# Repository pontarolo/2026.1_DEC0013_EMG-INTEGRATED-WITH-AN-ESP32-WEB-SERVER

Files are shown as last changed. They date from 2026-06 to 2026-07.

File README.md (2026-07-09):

<div align="center">
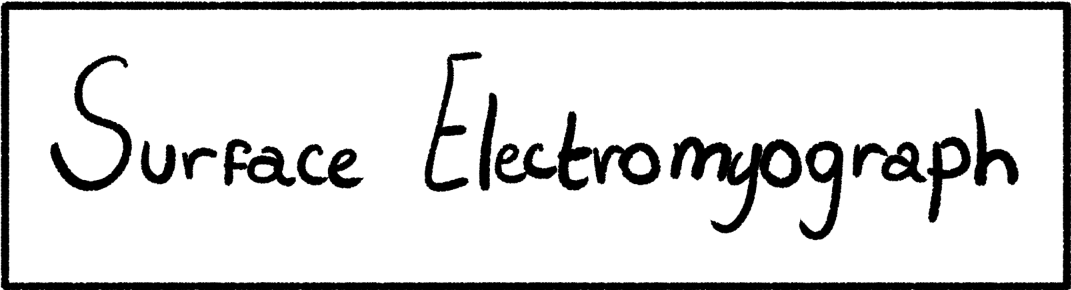
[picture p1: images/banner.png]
    
    

<h4 align="center">Electromyograph integrated with an ESP32 Web Server</h4>




</div>

<p align="center">
  <a href="#materials">Materials</a> •
  <a href="#diagrams">Diagrams</a> •
  <a href="software/README.md">Software</a> •
  <a href="LICENSE">License</a>
</p>

---

## Basic Overview

This project consists of an implementation of a circuit to measure specific muscle activity, consisting of two channels, which means that it is possible to measure two muscles simultaneously. The project emerges as a way to detect muscular issues and restraints in a low-cost and reliable manner. The general architecture of this project is a connection between the electromyograph PCB and the ESP32 microcontroller, where the ESP32 acts as a web server with an WebSocket to handle the data plotting. The GIF shown above was made from a video of the electromyograph in operation, which recorded the web page hosted by the ESP32.

## Goals

| Type | Goal |
| :--- | :--- |
| **Hardware** | Design a circuit that is capable of effectively measuring muscle voltage |
| **Hardware** | Make the circuit as noise-free as possible |
| **Software** | Write an optimized code that can display, in real time, the muscle data |

### Project Directory Structure

```text
├── hardware/             # PCB design files (symbols, footprints, models, and Gerbers)
│   ├── footprints/       # Custom component footprints (.kicad_mod)
│   ├── kicad_files/      # KiCad project files and manufacturing Gerbers
│   ├── models/           # 3D step files for components
│   └── symbols/          # Custom schematic symbol libraries (.kicad_sym)
├── images/               # Visual assets for documentation and tutorials
└── software/             # Firmware and source code for the project
    └── plot/             # ESP32 source code for data acquisition
```

## Description

This section explains the details of the project, including the materials and tools used, communication and electrical diagrams and examples of its functionality.

###  Materials

<table>
  <tr>
    <td align="center" valign="top" width="150" style="border: none;">
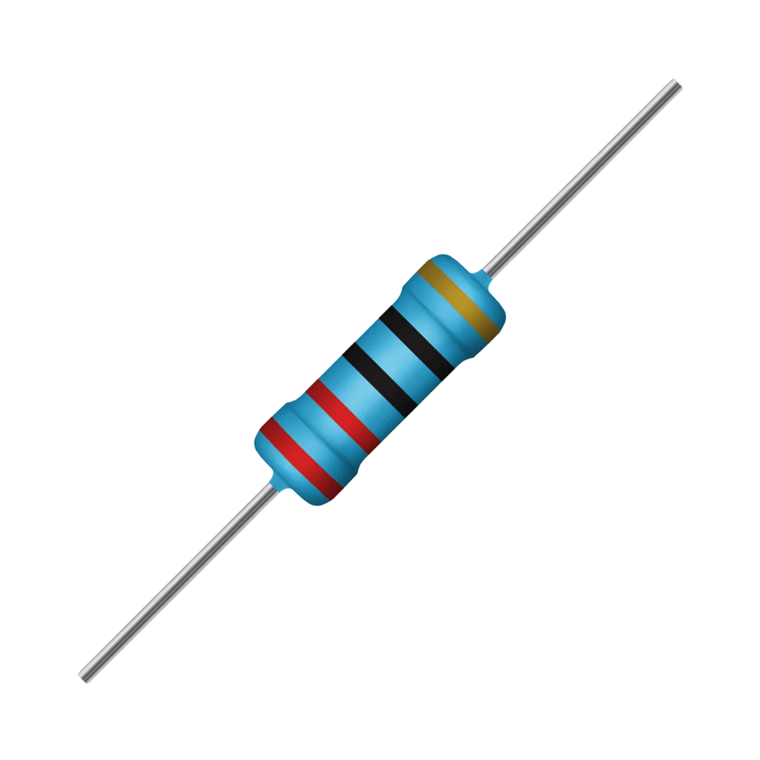
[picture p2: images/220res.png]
      <br>
      <strong>Resistor</strong><br>
      <font color="#666" size="2">2x 220Ω • 1/4 W • 5% • THT</font>
    </td>
    <td align="center" valign="top" width="150" style="border: none;">
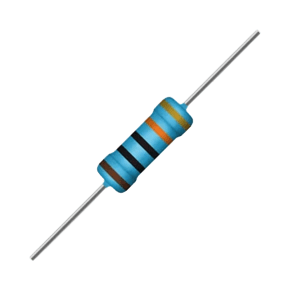
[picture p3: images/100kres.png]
      <br>
      <strong>Resistor</strong><br>
      <font color="#666" size="2">4x 100KΩ • 1/4 W • 5% • THT</font>
    </td>
    <td align="center" valign="top" width="150" style="border: none;">
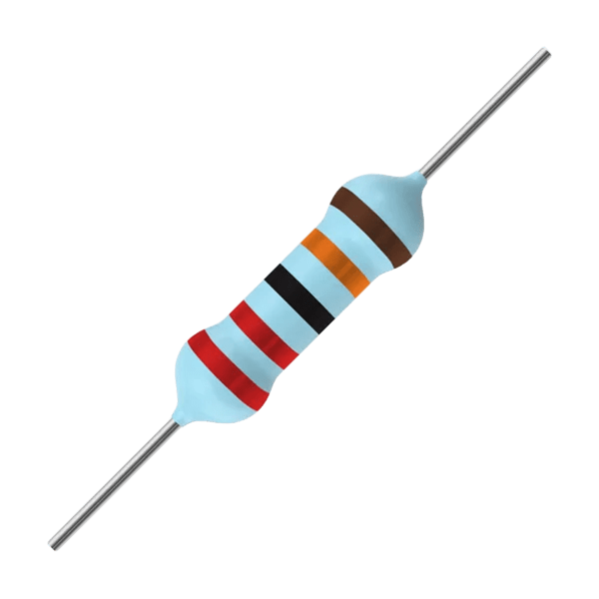
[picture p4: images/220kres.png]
      <br>
      <strong>Resistor</strong><br>
      <font color="#666" size="2">4x 220KΩ • 1/4 W • 5% • THT</font>
    </td>
    <td align="center" valign="top" width="150" style="border: none;">
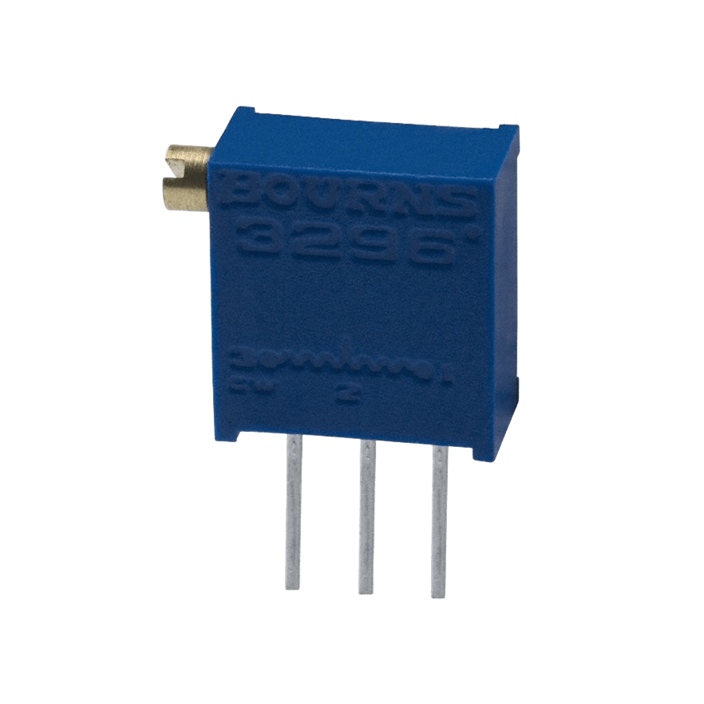
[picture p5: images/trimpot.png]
      <br>
      <strong>Trimpot</strong><br>
      <font color="#666" size="2">1x 10KΩ • THT</font>
    </td>
  </tr>
  <tr>
    <td align="center" valign="top" width="150" style="border: none;">
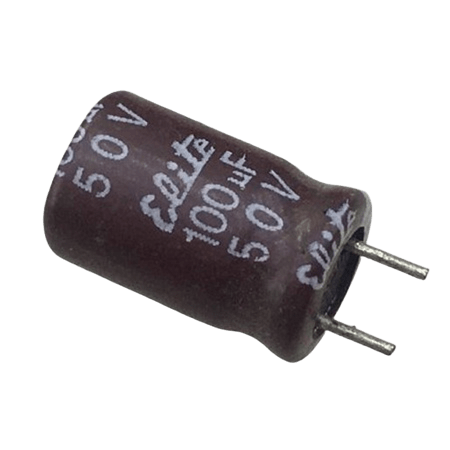
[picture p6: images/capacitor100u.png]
      <br>
      <strong>Capacitor</strong><br>
      <font color="#666" size="2">2x 100μF • Electrolytic • THT</font>
    </td>
    <td align="center" valign="top" width="150" style="border: none;">
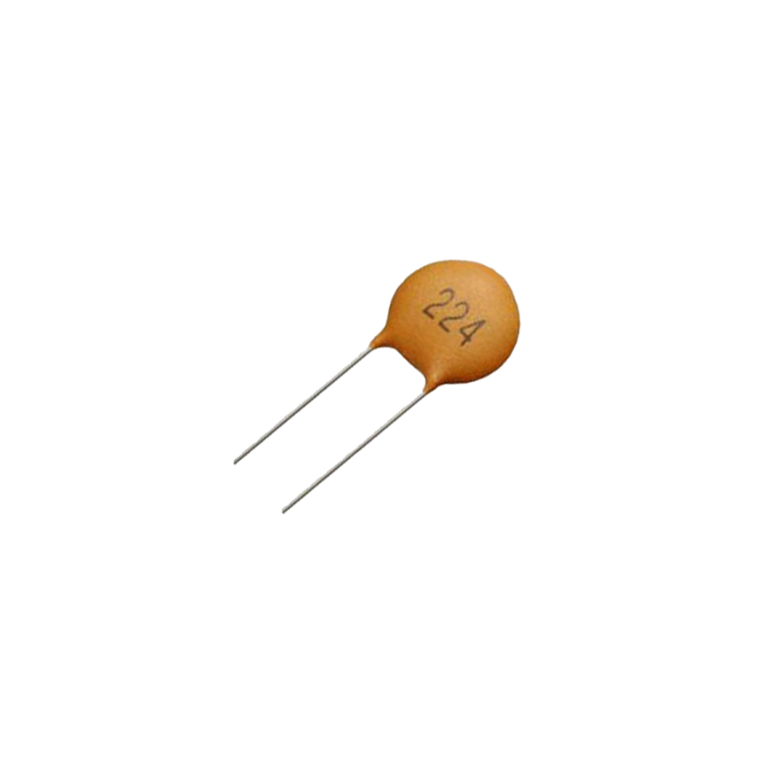
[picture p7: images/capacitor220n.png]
      <br>
      <strong>Capacitor</strong><br>
      <font color="#666" size="2">2x 220nF • Ceramic • THT</font>
    </td>
    <td align="center" valign="top" width="150" style="border: none;">
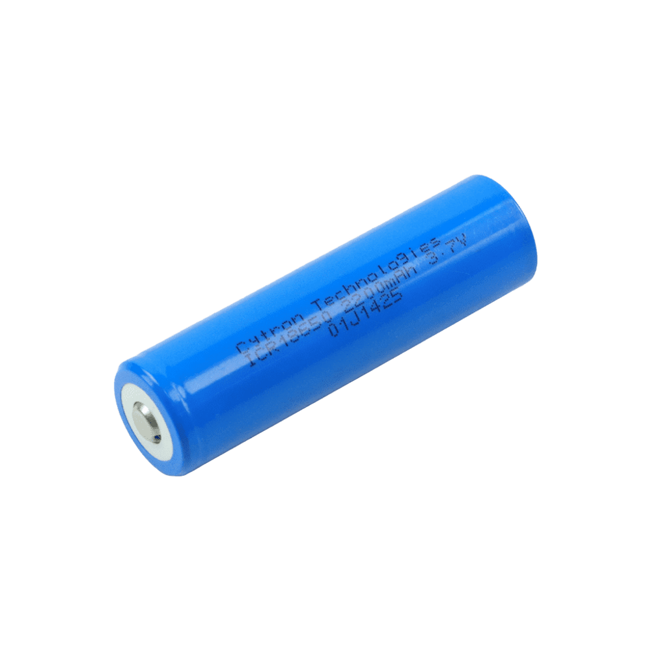
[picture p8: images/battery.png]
      <br>
      <strong>Battery</strong><br>
      <font color="#666" size="2">2x Lithium-Ion • 3.7V • 18650</font>
    </td>
    <td align="center" valign="top" width="150" style="border: none;">
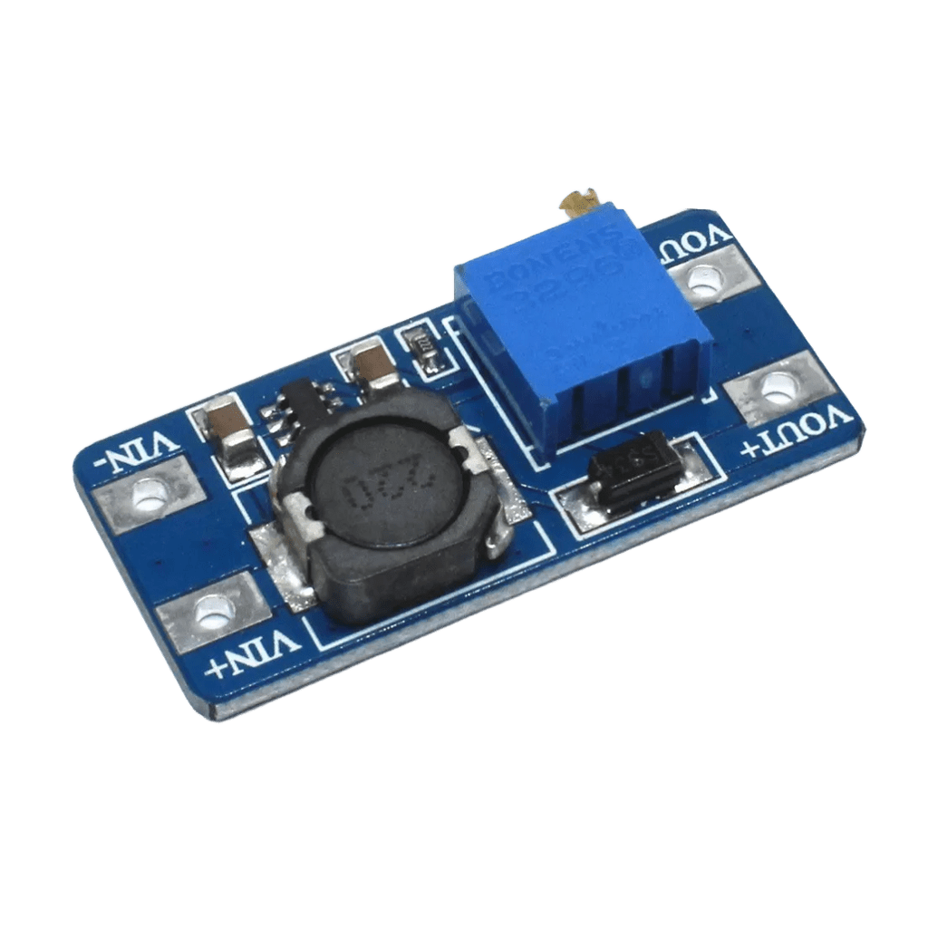
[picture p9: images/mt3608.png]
      <br>
      <strong>MT3608</strong><br>
      <font color="#666" size="2">1x Module</font>
    </td>
  </tr>
  <tr>
    <td align="center" valign="top" width="150" style="border: none;">
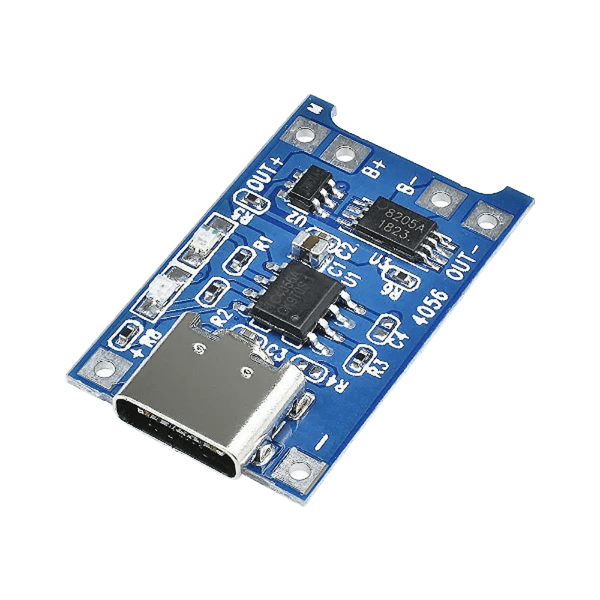
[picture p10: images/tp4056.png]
      <br>
      <strong>TP4056</strong><br>
      <font color="#666" size="2">1x Module</font>
    </td>
    <td align="center" valign="top" width="150" style="border: none;">
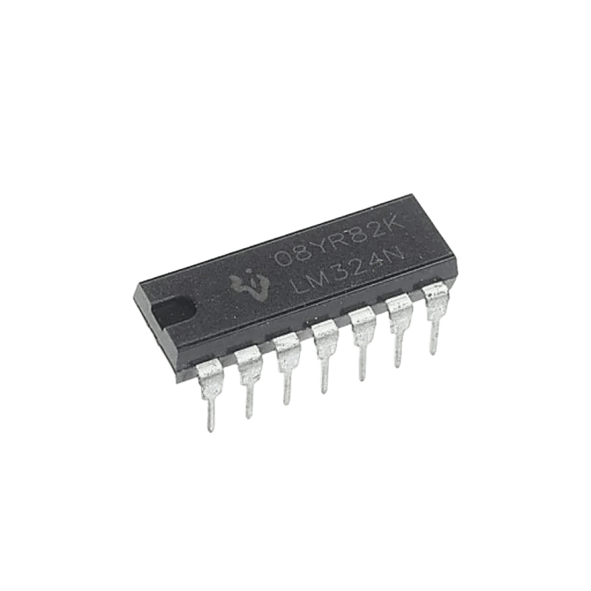
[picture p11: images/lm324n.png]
      <br>
      <strong>LM324N</strong><br>
      <font color="#666" size="2">1x Integrated Circuit</font>
    </td>
    <td align="center" valign="top" width="150" style="border: none;">
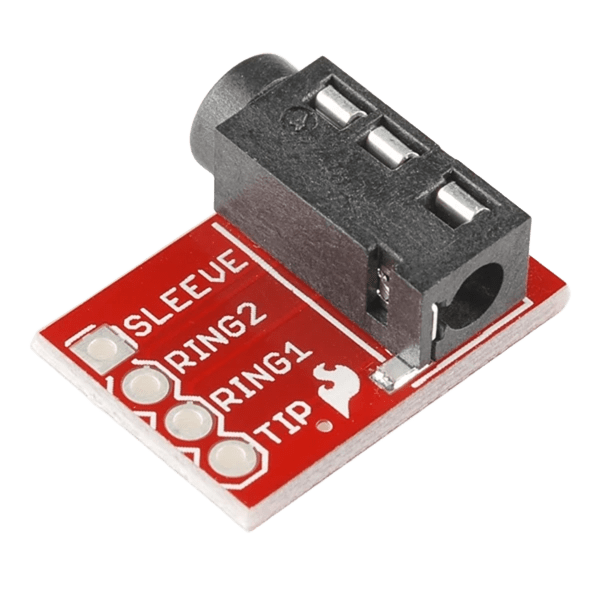
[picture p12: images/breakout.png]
      <br>
      <strong>TRRS Breakout</strong><br>
      <font color="#666" size="2">1x Module</font>
    </td>
    <td align="center" valign="top" width="150" style="border: none;">
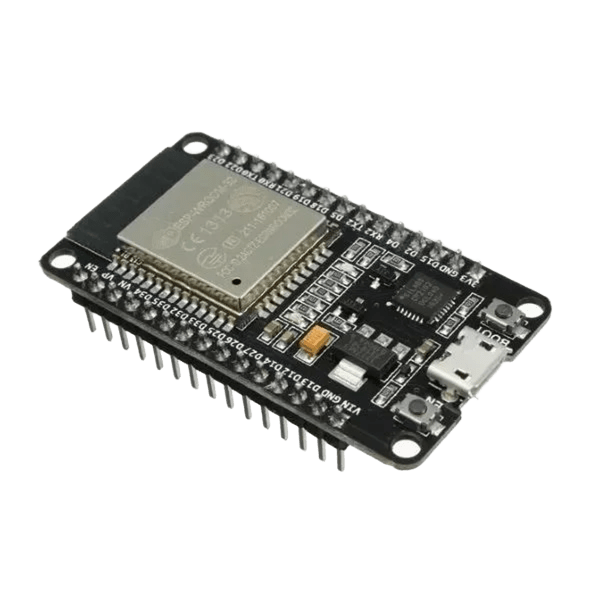
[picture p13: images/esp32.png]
      <br>
      <strong>ESP32</strong><br>
      <font color="#666" size="2">1x ESP-WROOM-32</font>
    </td>
  </tr>
  <tr>
    <td align="center" valign="top" width="150" style="border: none;">
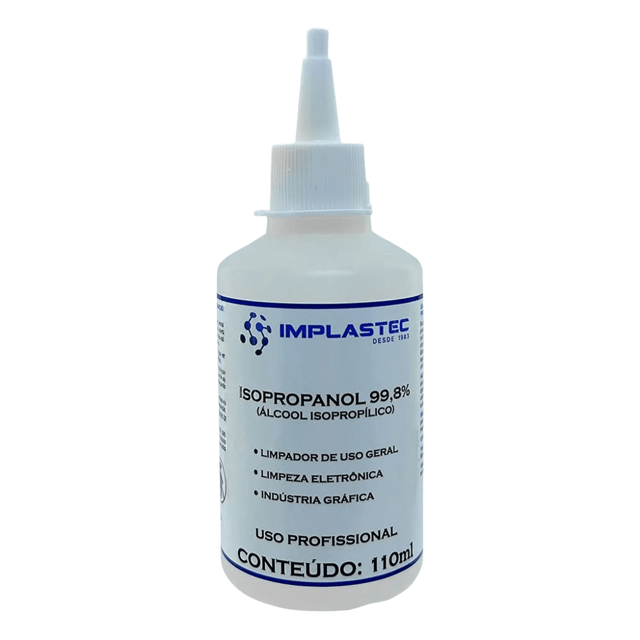
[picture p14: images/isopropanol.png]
      <br>
      <strong>Isopropanol</strong><br>
      <font color="#666" size="2">1x 99.8% Pure</font>
    </td>
    <td align="center" valign="top" width="150" style="border: none;">
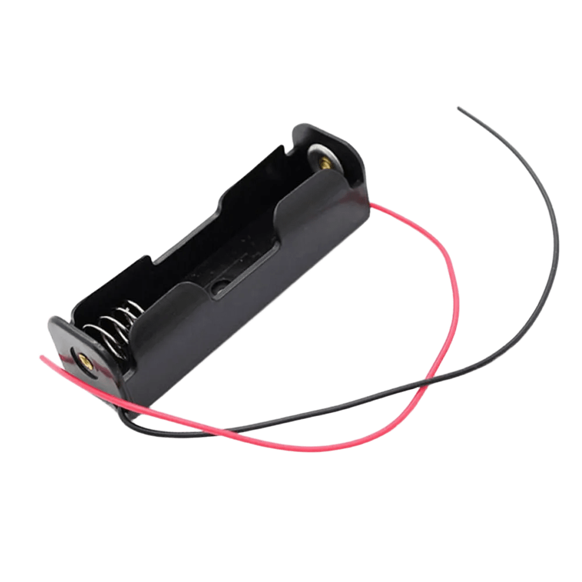
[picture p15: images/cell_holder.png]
      <br>
      <strong>Cell Holder</strong><br>
      <font color="#666" size="2">1x Lithium-Ion • 18650 • Single</font>
    </td>
    <td align="center" valign="top" width="150" style="border: none;">
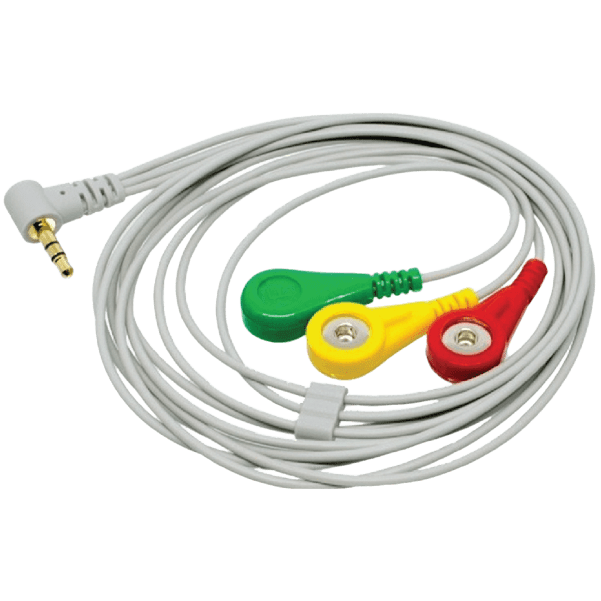
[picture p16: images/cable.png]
      <br>
      <strong>EMG Cable</strong><br>
      <font color="#666" size="2">2x P2 Connection</font>
    </td>
    <td align="center" valign="top" width="150" style="border: none;">
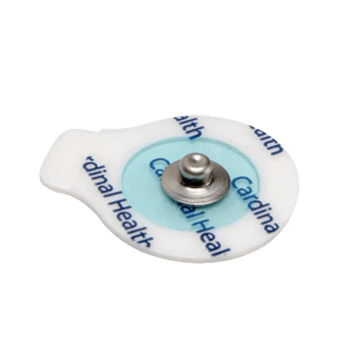
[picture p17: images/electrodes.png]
      <br>
      <strong>Electrodes</strong><br>
      <font color="#666" size="2">6x Disposable</font>
    </td>
  </tr>
</table>

###  Communication Diagram

In this subsection we will discuss the communication diagram of the project to give a general view of the signal path and a clearer understanding of the circuit itself.

<p align="center">
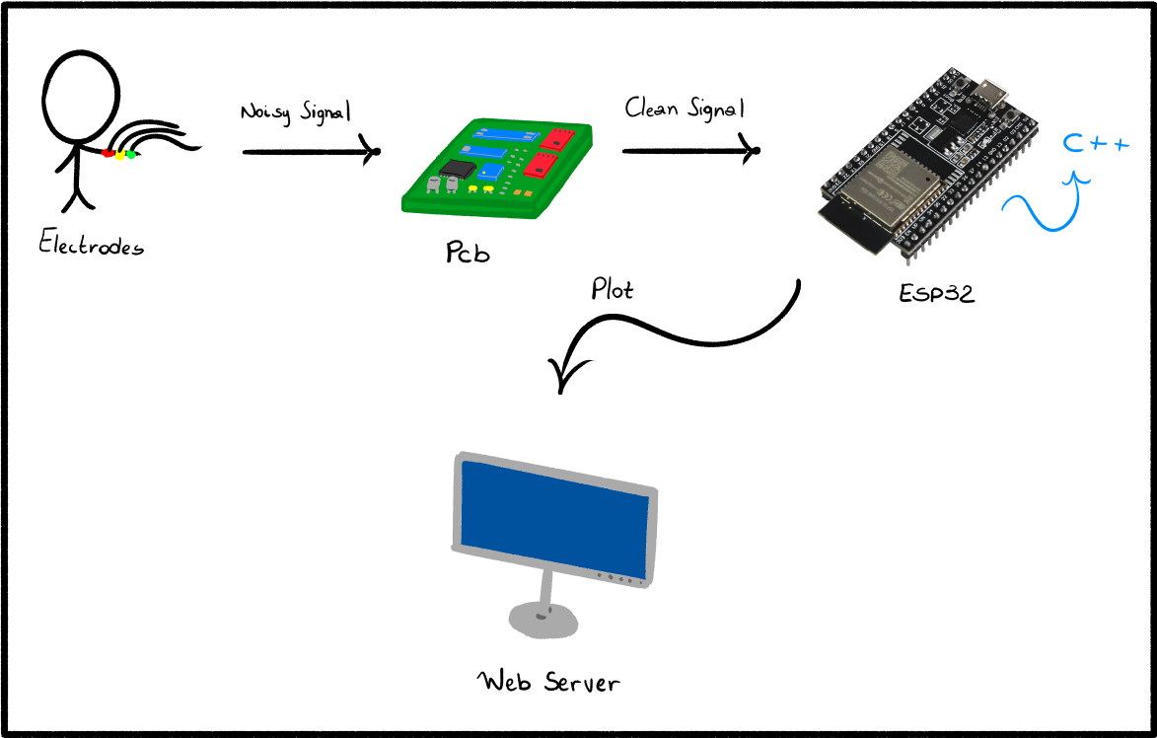
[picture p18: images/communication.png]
    
</p>

The image above represents the communication diagram, which shows the signal path throughout the whole project. The user's noisy low-voltage signal is sent to the printed circuit board (PCB) through silver $Ag$ or silver chloride $AgCl$ electrodes, where it can be properly filtered and amplified. Then the clean signal is carried to the ESP32 microcontroller that acts as a WebSocket Server to handle massive data plotting, hosting an HTML page that displays the graph.

---

###  Electrical Diagram

In this subsection we will discuss the communication diagram of the project to give a general view of the signal processing and a clearer understanding of the circuit itself.

<p align="center">
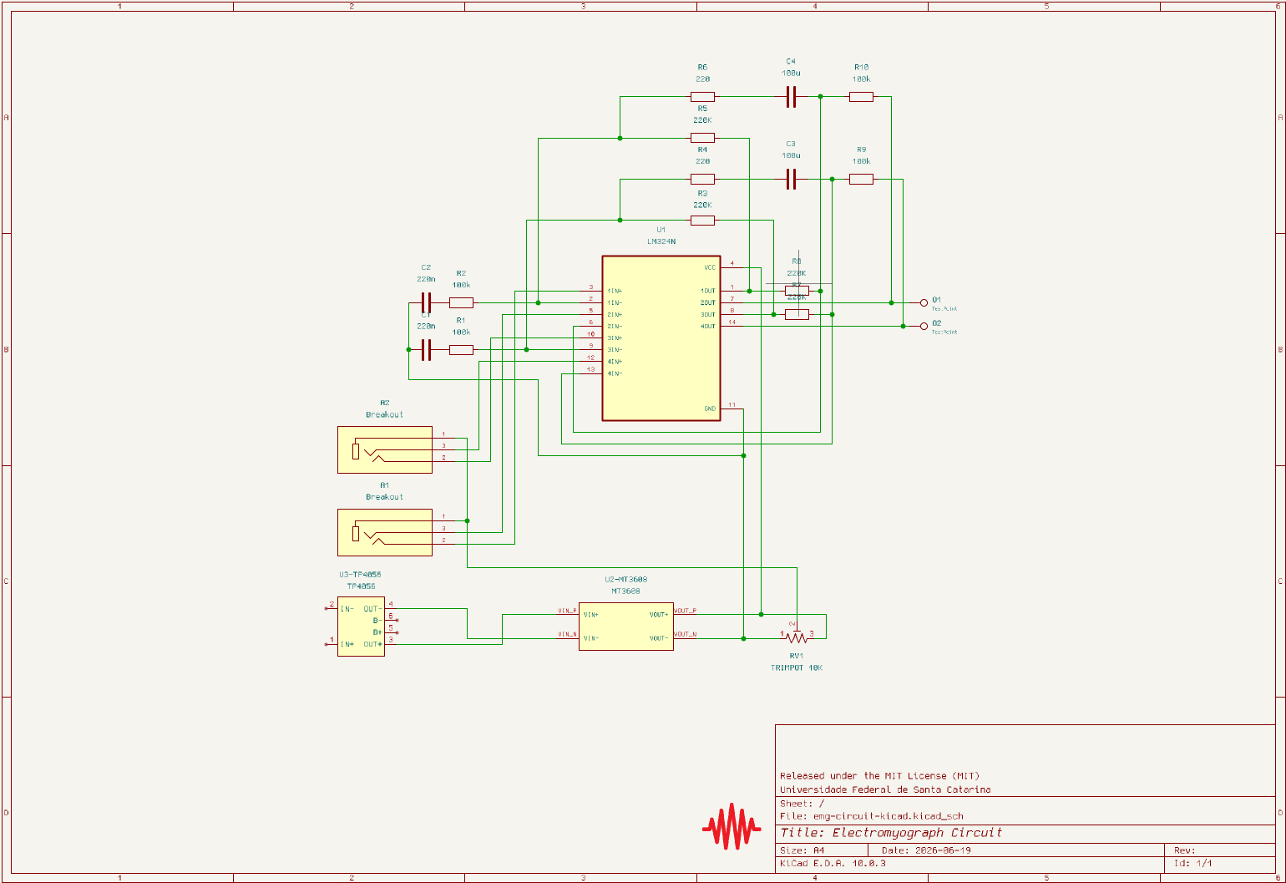
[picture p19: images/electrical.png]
    
</p>

The image above represents the electrical diagram, which shows the electrical connection between the components. As shown in the image, the circuit consists of:

| Component | Role in the circuit |
| :--- | :--- |
| **Resistors** | Set the gain stages, establish amplifier feedback loops, and stabilize signal lines. |
| **Trimpot** | Adjusts the virtual ground offset (reference voltage) to bias the EMG signal for the ESP32 ADC. |
| **Capacitors** | Filter out DC offsets (high-pass) and high-frequency noise (low-pass), and decouple power rails. |
| **Battery** | Provides clean, isolated 3.7V power to eliminate grid noise ($60\text{ Hz}$) and ensure user safety. |
| **MT3608** | Boosts the 3.7V battery to a stable 5V, ensuring full dynamic range for the op-amps. |
| **TP4056** | Handles safe Li-Ion battery charging and provides over-discharge protection. |
| **LM324N** | Handles differential amplification and active filtering of the microvolt-level muscle signals. |
| **TRRS Breakout** | Serves as the input jack for the 3-lead electrode cable (Signal +, Signal -, and Reference). |
| **ESP32 (Implicit)** | Samples the analog processed signal and hosts the WebSocket server for real-time live plotting. |

<p align="center">
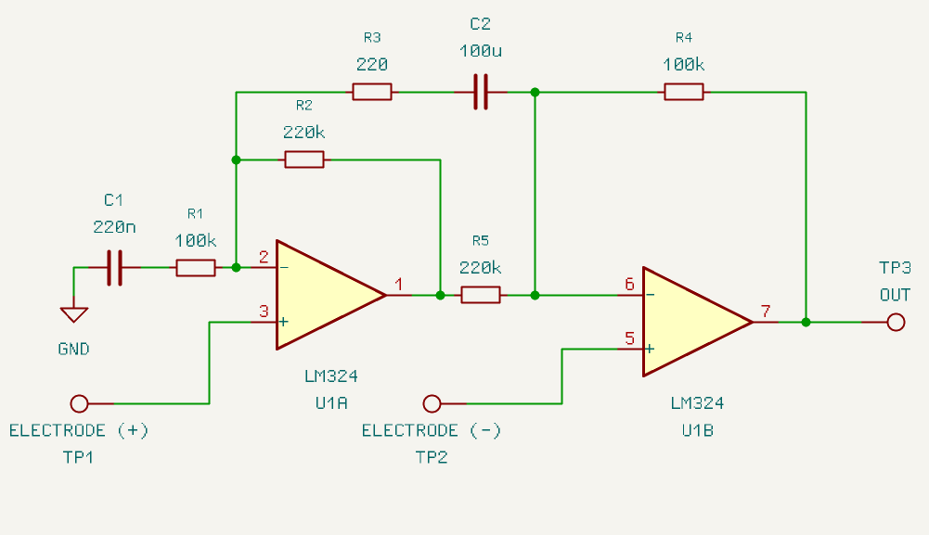
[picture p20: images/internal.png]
    
</p>

To secure the right voltage for the ESP32 ADC pins, a set of calculations were made, using the following equations:

- **Op-Amps:** By applying Kirchhoff's Laws, it is possible to obtain the expressions for Common and Differential Mode Gain:

| Name | Equation |
| :--- | :--- |
| **Common Mode Voltage** | $V_{cm} = \frac{V_{electrode(+)} + V_{electrode(-)}}{2}$ |
| **Common Mode Gain** | $A_{cm} = 1 - \frac{R_4}{Z_1}$ |
| **Differential Mode Voltage** | $V_{dif} = V_{electrode(+)} - V_{electrode(-)}$ |
| **Differential Mode Gain** | $A_{dif} = -\left(\frac{1}{2} + \frac{R_4}{R_5} + \frac{2R_4}{Z_3} + \frac{R_4}{2Z_1}\right)$ |

Where the complex impedances $Z_1$ and $Z_3$ are defined in the frequency domain ($s$-domain) as:

| Name | Equation |
| :--- | :--- |
| **Impedance $Z_1$** | $Z_1(s) = R_1 + \frac{1}{sC_1}$ |
| **Impedance $Z_3$** | $Z_3(s) = R_3 + \frac{1}{sC_2}$ |

By substituting the values, it follows that the circuit raises the muscle voltage by around $1000$ times.

<p align="center">
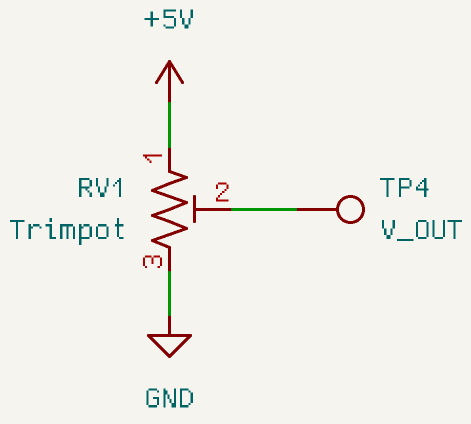
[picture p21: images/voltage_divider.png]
    
</p>

- **Voltage Divider:** To reach a desired reference voltage, the following equation can be used:

| Name | Equation |
| :--- | :--- |
| **Reference Voltage** | $V_{out} = \left(5V\right)\left(\frac{R_{variable}}{R_{total}}\right)$ |

So, to adjust the center of the signal (reference), it is needed to setup the trimpot resistance to match the desired voltage.

---

### Pin Reference

<p align="center">
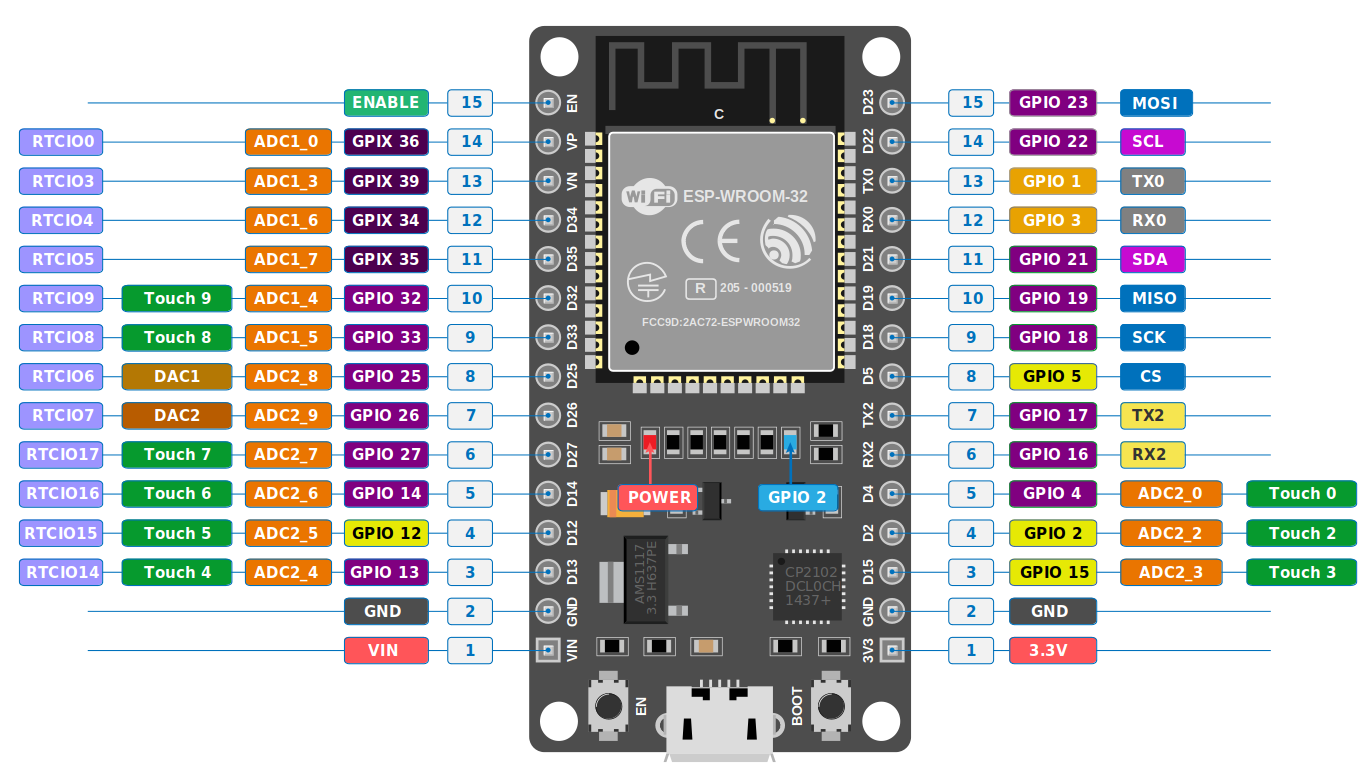
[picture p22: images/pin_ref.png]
    
</p>

For reference look at the <a href="#electrical">Electrical Diagram</a>.

| Pin Number | Connected to |
| :--- | :--- |
| **Pin 1** | VOUT_P (MT3608) |
| **Pin 2** | VOUT_N (MT3608) |
| **Pin 11** | O1 (Output 1) |
| **Pin 12** | O2 (Output 2) |

All the others are **disconnected**.

> [!IMPORTANT]  
> Even though the project has only one graph, both of the outputs needs to be connected. The first output (O1) is the main channel, and the second output (O2) is an auxiliar channel that helps in cleaning the noise.

---

## Prototype

A single-channel prototype was implemented on a breadboard to validate the circuit's functionality during the testing phase. The prototype can be seen in the image below.

<p align="center">
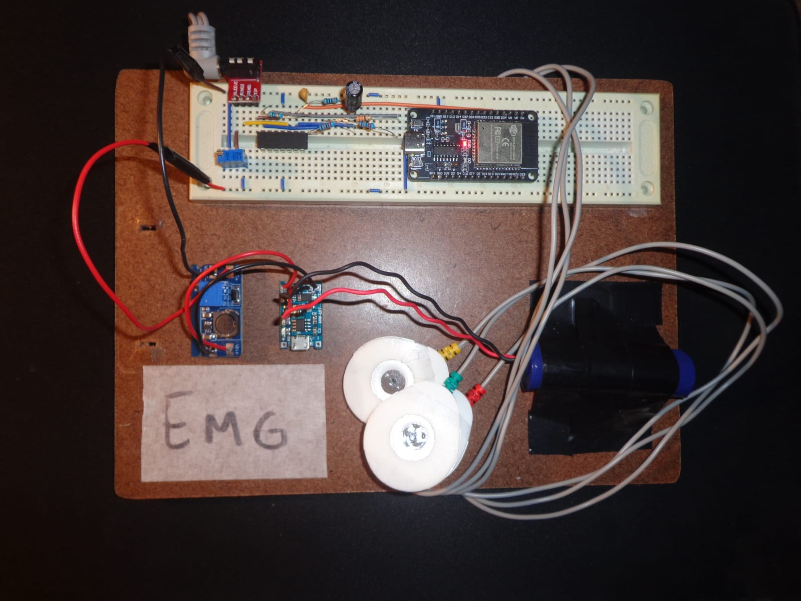
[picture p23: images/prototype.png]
    
</p>

---

## Final Assembly and PCB Layout

In the images below, it is shown the final assembly, consisting of two main blocks, the printed circuit board (PCB), which was ordered from <a href="https://jlcpcb.com/">JLCPCB</a>, and the ESP32 microcontroller, and the printed circuit board (PCB) layout.

<p align="center">
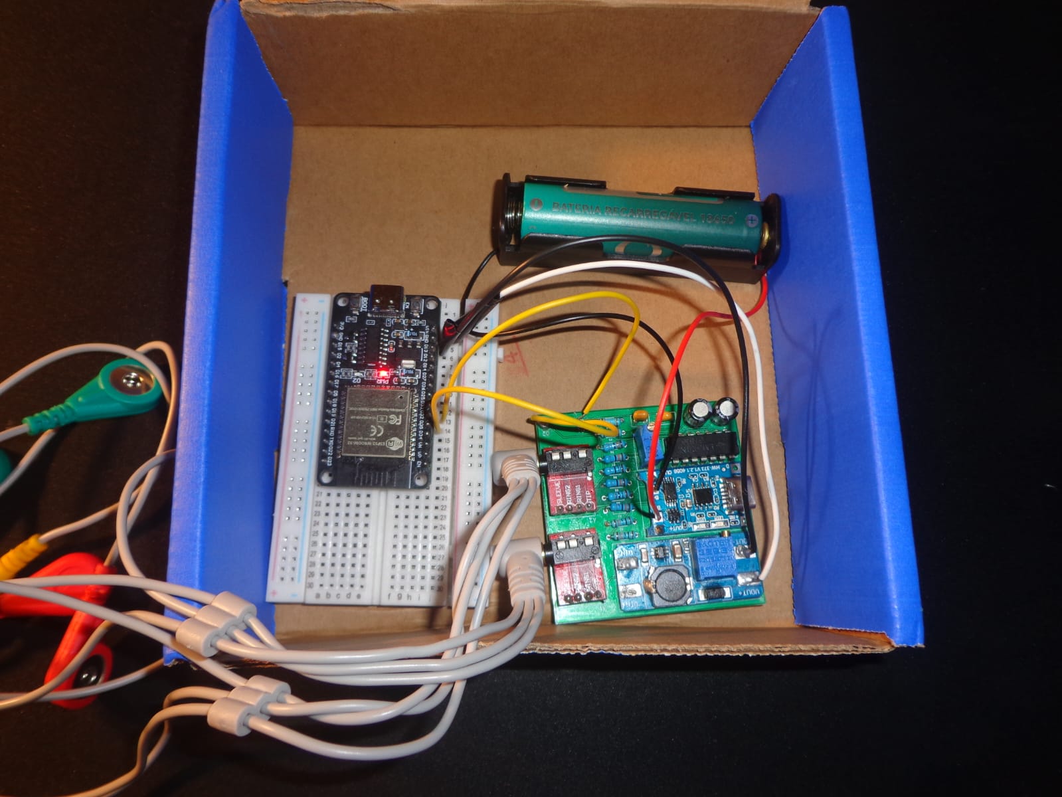
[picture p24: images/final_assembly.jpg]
    
</p>

<p align="center">
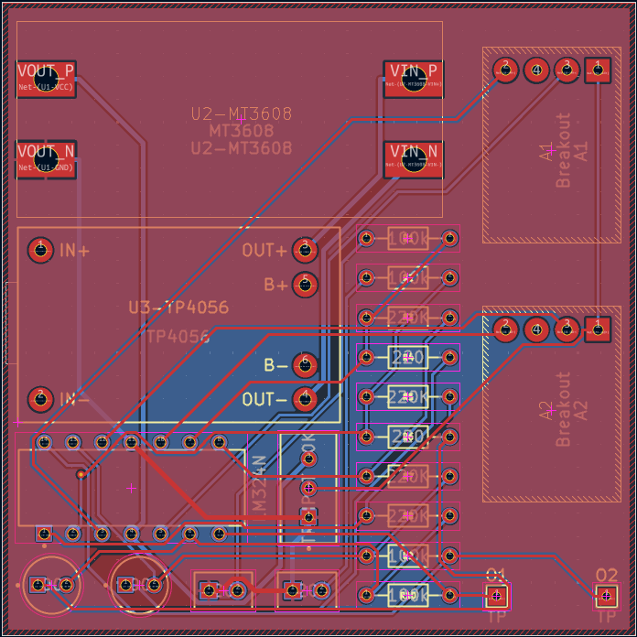
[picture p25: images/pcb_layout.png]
    
</p>

> [!TIP]
> In environments highly susceptible to noise, such as an electromyograph, it is important to clean the board with isopropanol and an anti-static brush to remove any soldering residue.

To help reduce the noise, it was used copper pouring in both layers of the printed circuit board (PCB). In the table below it is presented some important parameters of the board.

| Parameter | Value |
| :--- | :--- |
| **Power Trace Width** | $0.4 \ mm$ |
| **Signal Trace Width** | $0.2 \ mm$ |
| **Clearance** | $0.2 \ mm$ |
| **Via Size** | $0.6 \ mm$ |
| **Via Hole** | $0.3 \ mm$ |
| **μVia Size** | $0.3 \ mm$ |
| **μVia Hole** | $0.1 \ mm$ |
| **DP Width** | $0.2 \ mm$ |
| **DP Gap** | $0.25 \ mm$ |

---

## Electrode Placement

<p align="center">
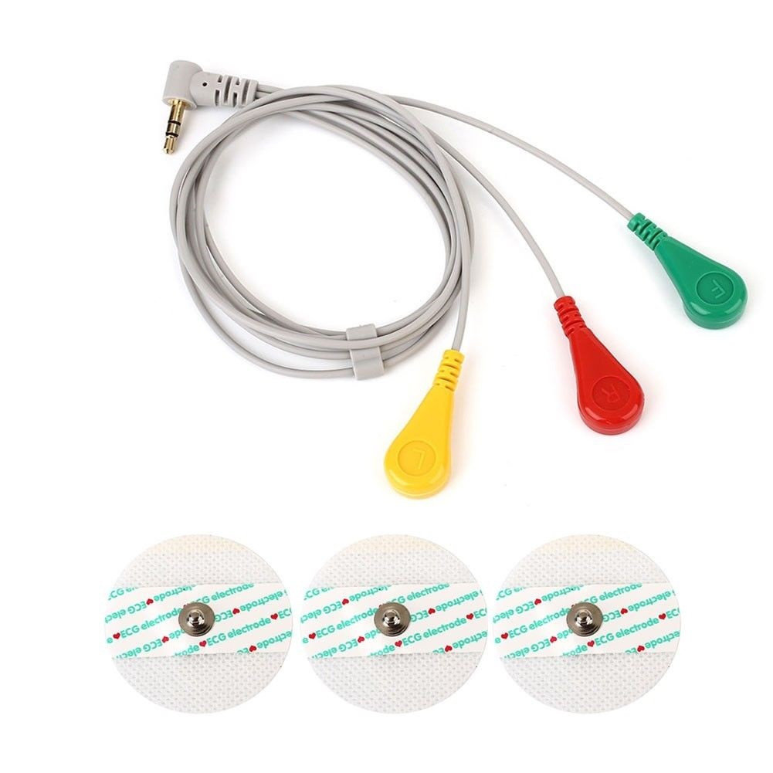
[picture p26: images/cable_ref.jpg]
    
</p>

| Cable End | Role |
| :--- | :--- |
| **Yellow** | Reference |
| **Green** | Negative |
| **Red** | Positive |

> [!IMPORTANT]  
> Place the yellow electrode in a non-muscular part of the body, and the centers of green and red electrodes within 2 centimeters apart along the desired muscle fibers.

---

## Software Used

To install the software, click on the name and you will be redirected to the download page. 

<table>
  <tr>
    <td align="center" valign="top" width="120" style="border: none;">
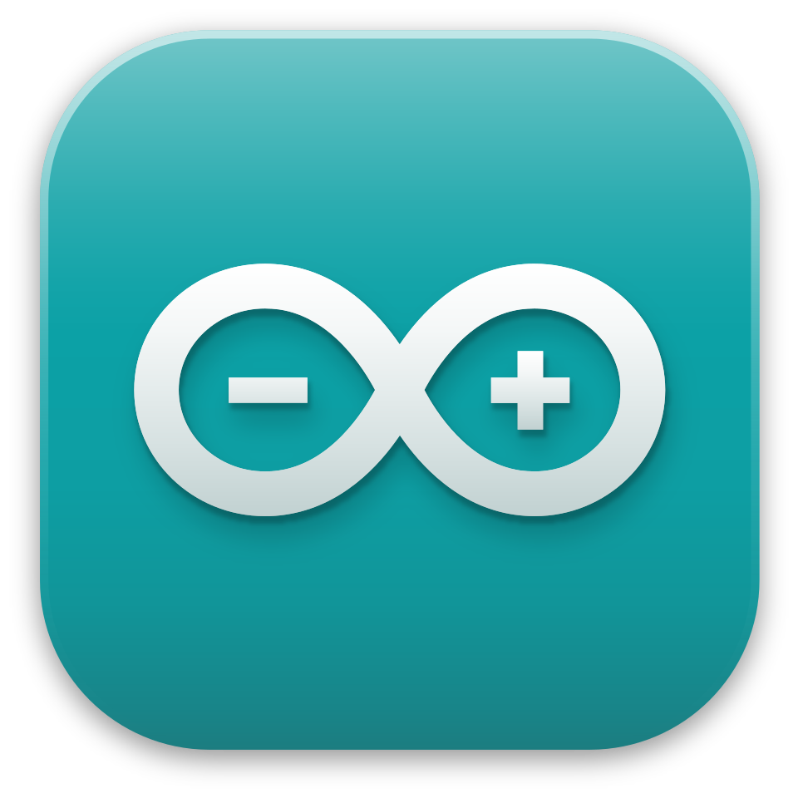
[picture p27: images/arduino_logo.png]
Arduino Logo
      <br>
      <strong><a href="https://www.arduino.cc/en/software/">Arduino IDE</a></strong><br>
      <font color="#666" size="2">v2.3.8</font>
    </td>
        <td align="center" valign="top" width="120" style="border: none;">
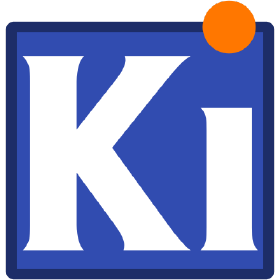
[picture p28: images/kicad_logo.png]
KiCad Logo
      <br>
      <strong><a href="https://www.kicad.org/download/">KiCad</a></strong><br>
      <font color="#666" size="2">v10.0.2</font>
    </td>
     </td>
        <td align="center" valign="top" width="120" style="border: none;">
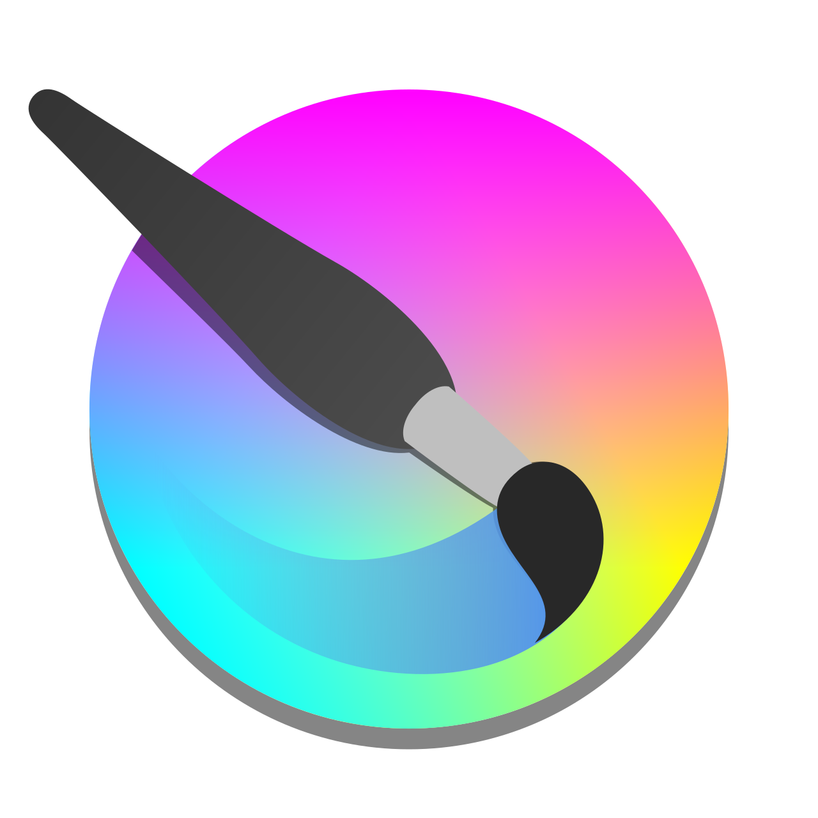
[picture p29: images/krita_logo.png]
Krita Logo
      <br>
      <strong><a href="https://krita.org/pt-br/download/">Krita</a></strong><br>
      <font color="#666" size="2">v6.0.2.1</font>
    </td>
  </tr>
</table>

## References

[1] Rodrigues, I. T., Bonfim, M. J., Miyazaki, D. R., da Fonseca, M. S. R. S., & da Silva Ferraz, R. Dispositivo de Aquisição de Sinais Eletromiograficos de Superfície para Monitoramento em Tempo Real.

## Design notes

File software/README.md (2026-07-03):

<p align="center">
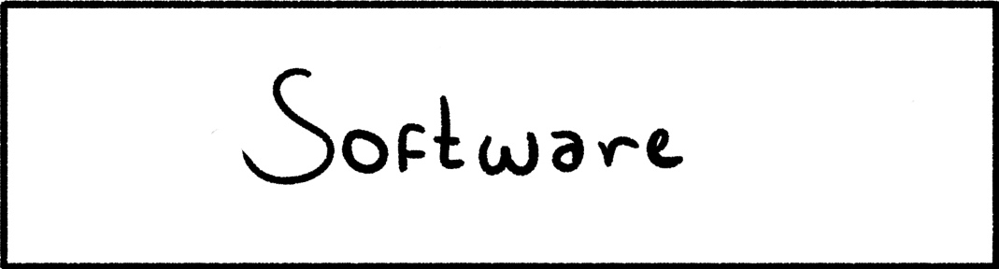
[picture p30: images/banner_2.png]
    
</p>

## Basic Overview

In this file, the main aspects of the software side of the project are covered, such as libraries used, the network setup, a brief explanation of the logic and how the data was plotted. It was added a tutorial on how to install the specific libraries and softwares at the end of this document. 

---

### Libraries

<p align="center">
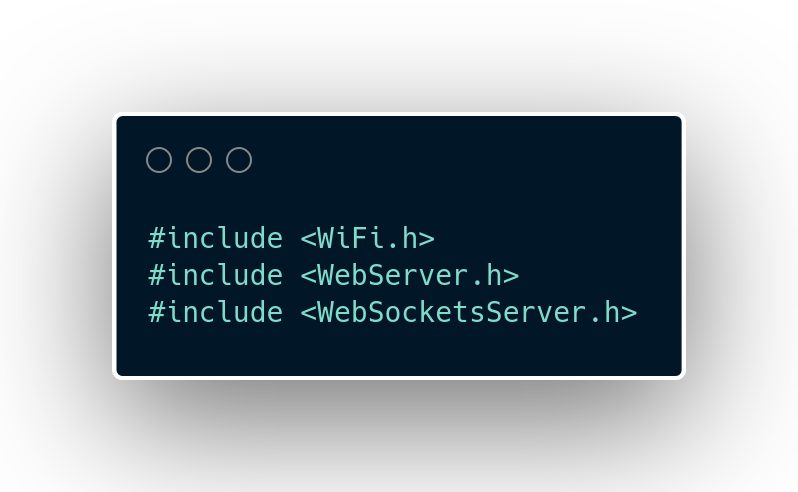
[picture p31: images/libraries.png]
    
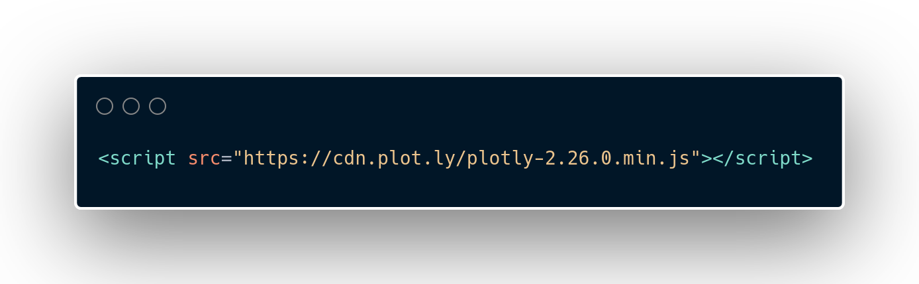
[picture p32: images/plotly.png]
    
</p>

In the images above, it is presented the part of the code where the libraries used in the project were declared. The libraries installed are the following

| Library | Version |
| :--- | :--- |
| **Async TCP** | v3.4.10 |
| **ESP Async WebServer** | v3.11.1 |
| **WebSockets** | v2.7.2 |
| **Plotly** | v2.26.0 |

The **Async TCP**, **ESP Async WebServer** and the **WebSockets** library are used for the Web Server, **Plotly** in the other hand is used to handle the massive data plotting and displaying it nicely in a voltage against time graph.

---

### Setup

The **setup** function that is presented below initializes the environment for an ESP32 or similar microcontroller to function as a web server.

<p align="center">
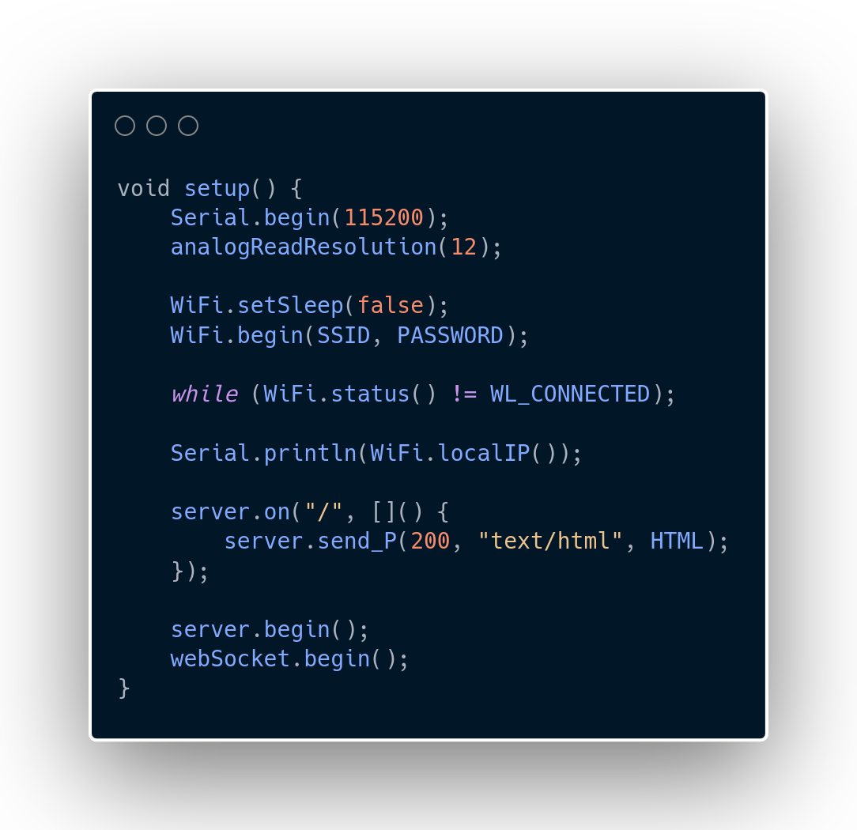
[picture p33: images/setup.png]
    
</p>

 It begins by configuring serial communication at **115200 baud** for debugging and setting the analog-to-digital converter to 12-bit resolution for precise readings. To ensure stable connectivity, the code disables WiFi sleep mode before initiating a connection to the specified network, blocking further execution until a valid IP address is assigned and printed to the serial monitor. Finally, it defines the web server's root route to serve static HTML content and formally starts the **WebSocket** server to enable real-time, bidirectional data communication with connected clients.

---

### Plotly Example

To efficiently handle continuous data streams from an ESP32, this implementation utilizes the **Plotly.js** library. The visualization process is effectively divided into two distinct phases: the initial setup of the graph container and the high-performance handling of incoming WebSocket data packets.

<p align="center">
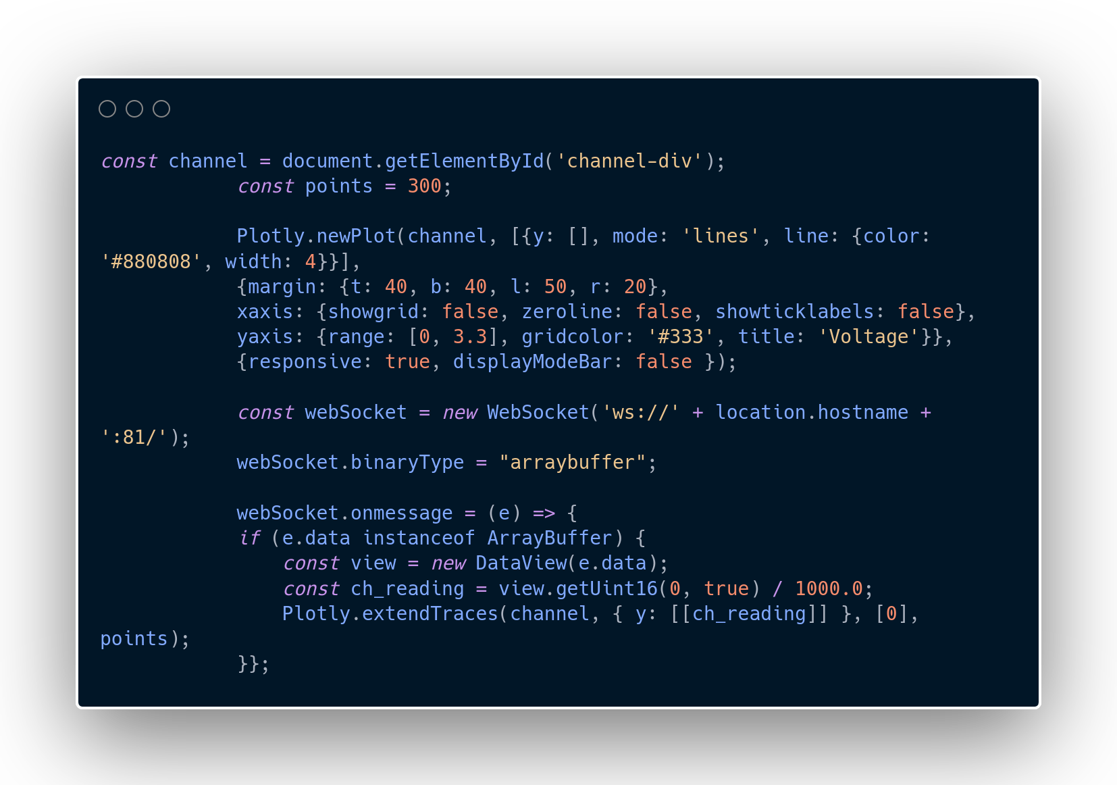
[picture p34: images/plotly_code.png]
    
</p>

The initialization phase is managed by the **Plotly.newPlot** function. This step defines the target **DOM** element for the chart and establishes the visual configuration, such as margin spacing and line styling. By setting the yaxis.range to [0, 3.3], the graph is correctly constrained to match the operating voltage of the **ESP32’s analog-to-digital converter** (ADC), ensuring that all incoming readings fit appropriately within the display area. Features like grid lines and the mode bar are also disabled here to minimize rendering overhead and maintain a cleaner user interface.

For real-time streaming, the **extendTraces** function is used instead of redrawing the entire graph, which is essential for performance. When the WebSocket receives a message, the data sent as an ArrayBuffer is parsed using a DataView. The raw 16-bit unsigned integer is converted into a meaningful voltage reading by dividing by 1000.0. This updated value is then passed to **extendTraces**, which efficiently appends the data point to the graph. By limiting the points variable to 300, the plot automatically maintains a smooth, sliding window effect that visualizes the signal in real-time without overwhelming the browser's resources. One can find more information about this library by accessing the official <a href="https://plotly.com/javascript/basic-charts/">website</a> for the library.

---

### Filtering

<p align="center">
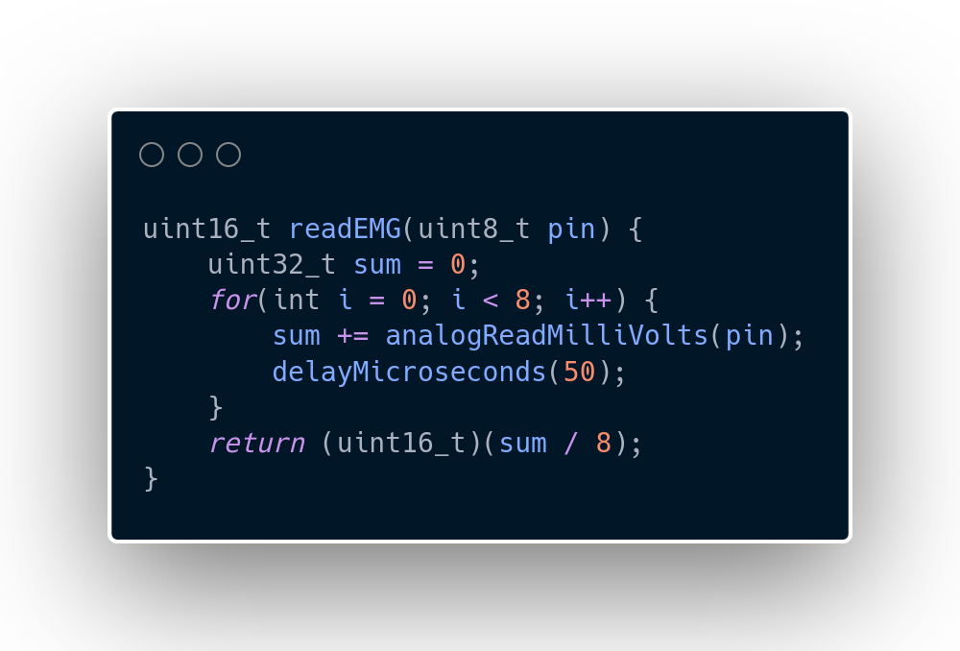
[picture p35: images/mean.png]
    
</p>

In the image above, it is shown a function that calculates the mean of the last eight readings from the pin specified in the parameter, helping in stabilizing the signal.

---

### Defines

<p align="center">
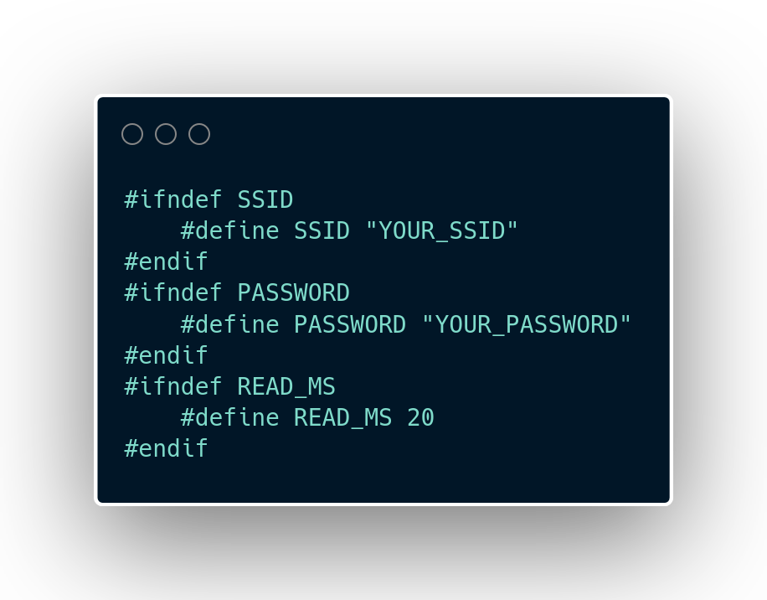
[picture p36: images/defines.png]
    
</p>

In the image above, it is shown the declaration of two constants (SSID and PASSWORD) that serve to setup the Web Server. If you wish to use this code, you will need to change **YOUR_SSID**, with your network SSID, and **YOUR_PASSWORD** with your network password in order to make the ESP32 work as a server. The third constant that can be seen in the image is **READ_MS**, which is a way to parametrize the delay between the readings of the electromyograph.

---

### Main Loop

<p align="center">
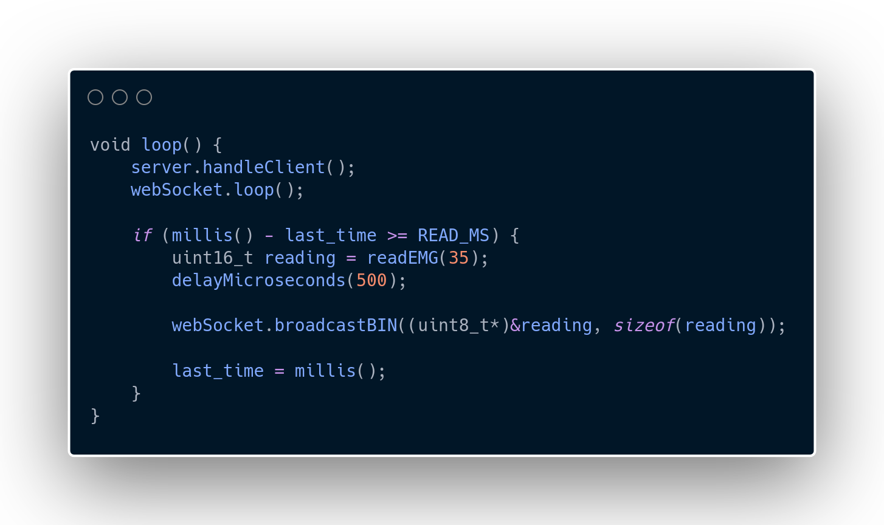
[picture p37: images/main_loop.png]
    
</p>

In the image above, it is shown the main loop. The thing here, is that we calculate the difference between the function **millis()** the variable **last_time** to get the time between the two last readings, but, the microcontroller can stutter if too many readings are made in a short period of time. To solve that, it is needed to use a threshold, in this case the constant **READ_MS**, only readings within time spans greater or equal than **READ_MS** are accepted. If you look inside of the if statement, there is a declaration of an variable that will hold the raw reading from the ESP32 analog to digital pin, and in the next line it is called a function to broadcast these in binary form, to optimize the microcontroller and prevent lagging.

---

### How to install the libraries

#### Arduino IDE

First open **Arduino IDE**, then you will see a bar on the left with an libraries button, represented with books, as shown in the image below.

<p align="center">
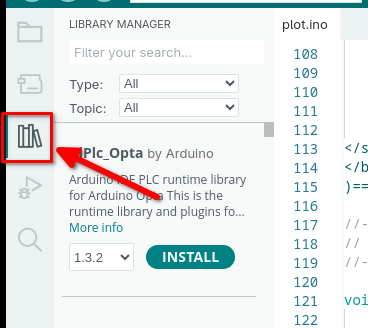
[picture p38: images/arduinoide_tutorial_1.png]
    
</p>

Type the desired library (**Async TCP**, **ESP Async WebServer** and **WebSockets**) in the search field and then click **INSTALL**.

<p align="center">
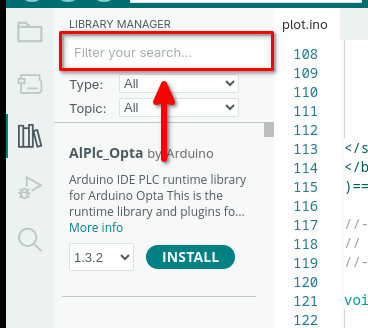
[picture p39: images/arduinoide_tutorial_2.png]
    
</p>

Notice that **Plotly** does not need to be installed, as it is imported from **CDN (Content Delivery Network)**.

#### KiCad

First open **KiCad**, then you will see in the top bar a section named **Preferences**, as shown in the image below.

<p align="center">
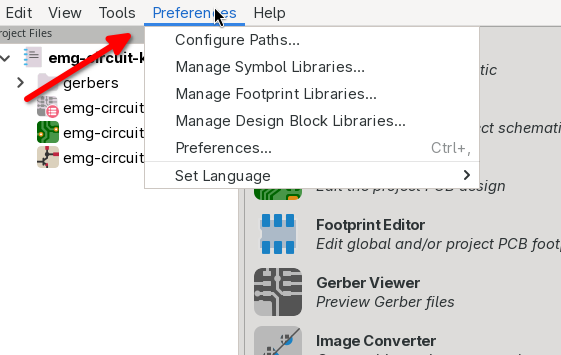
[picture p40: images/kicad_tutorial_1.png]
    
</p>

Then, click on **Manage Symbol Libraries**, and go to the **Project Specific Libraries** tab. Make sure that it looks something like the image below, if not, click on the plus sign and fill the fields as it is being presented.

<p align="center">
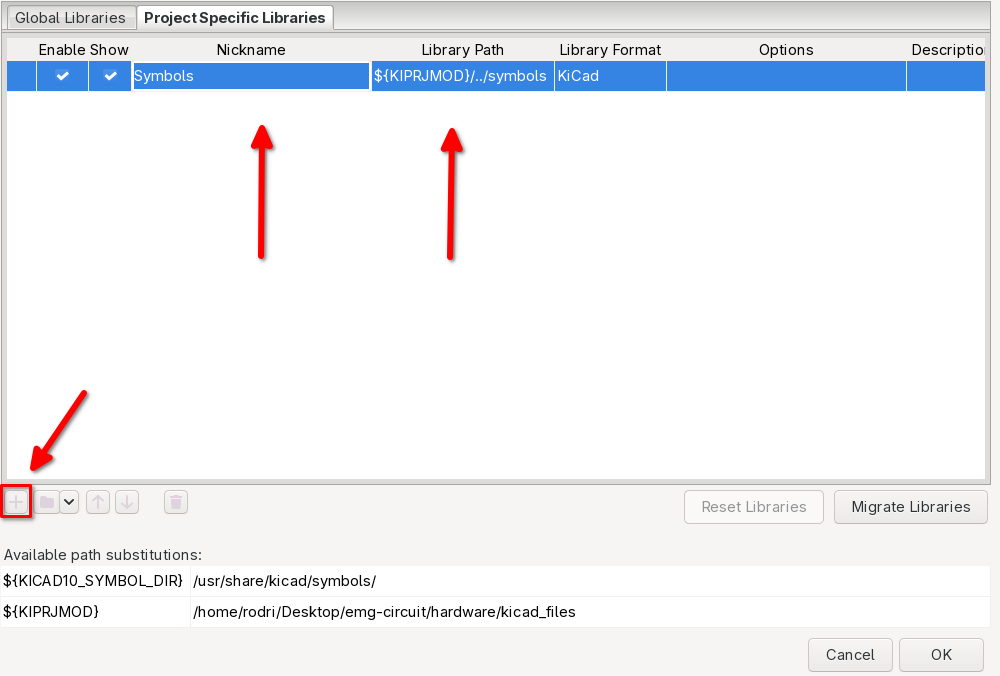
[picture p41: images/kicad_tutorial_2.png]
    
</p>

```
Symbols
```

```
${KIPRJMOD}/../symbols
```

Do the same verification for **Manage Footprint Libraries**, in the **Project Specific Libraries** tab.

<p align="center">
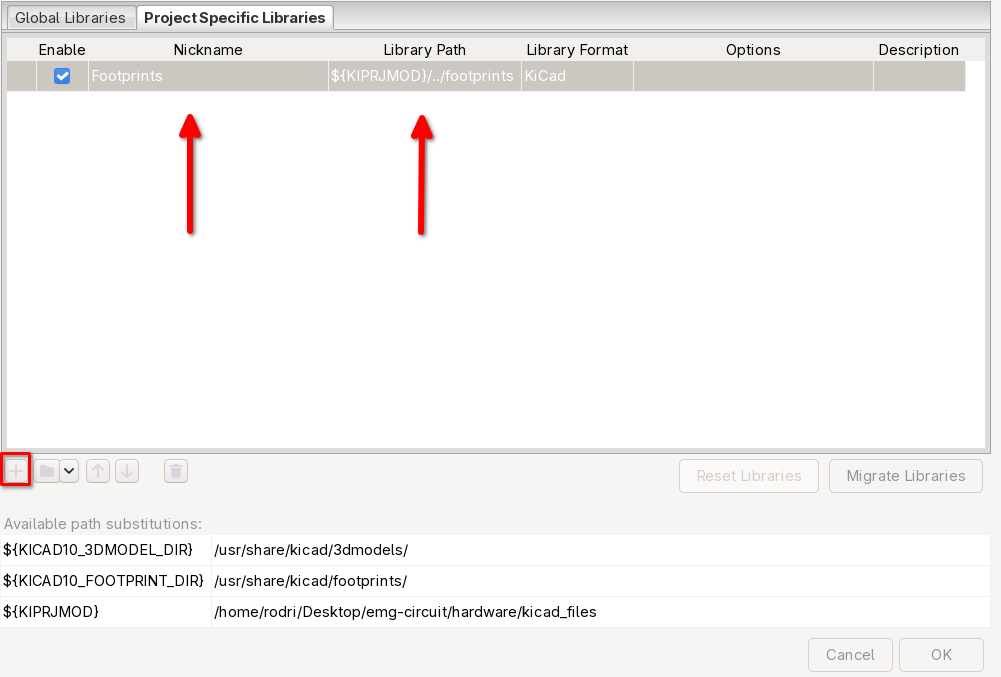
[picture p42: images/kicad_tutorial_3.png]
    
</p>

```
Footprints
```

```
${KIPRJMOD}/../footprints
```

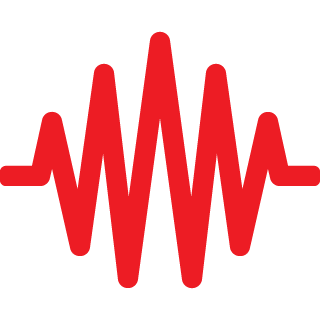
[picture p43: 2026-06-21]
images/signal.png

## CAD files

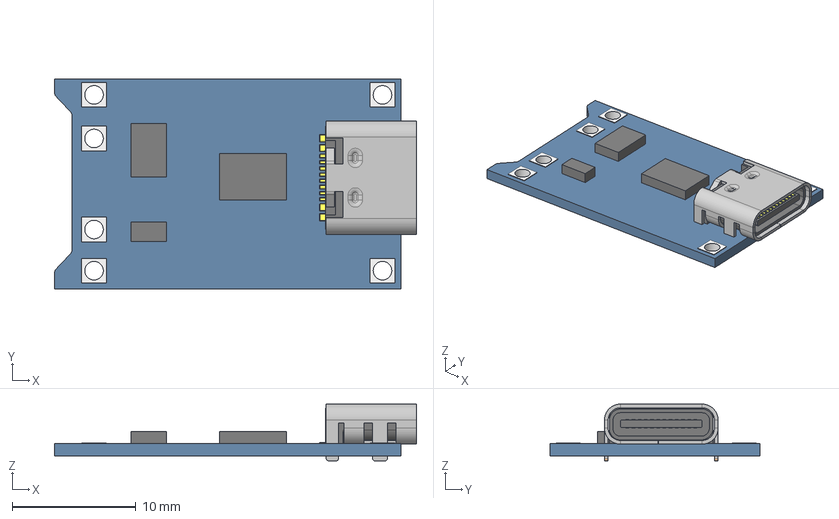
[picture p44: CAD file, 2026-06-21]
hardware/models/tp4056.step
29.3 x 17.0 x 4.60 mm

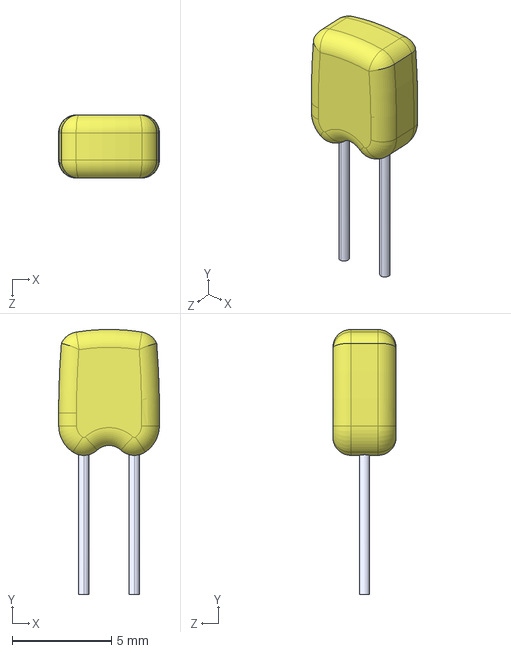
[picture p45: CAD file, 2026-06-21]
hardware/models/capacitor_220n.step
5.08 x 13.3 x 3.18 mm

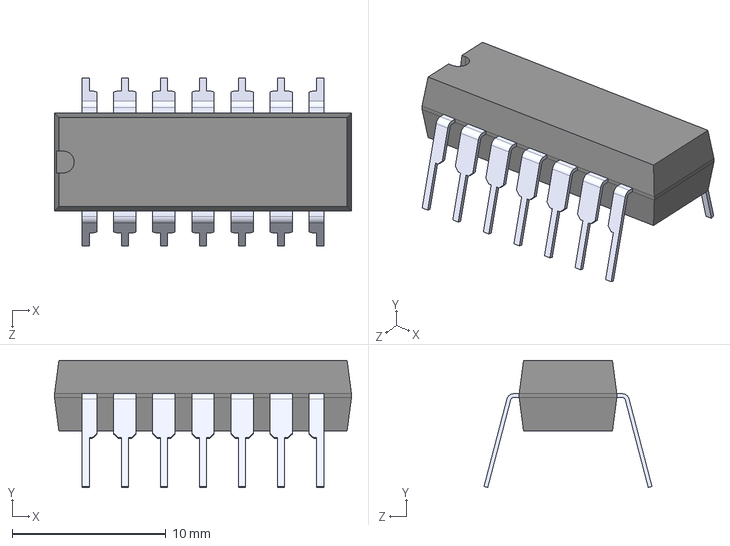
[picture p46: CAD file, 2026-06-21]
hardware/models/lm324.step
19.3 x 8.25 x 10.9 mm

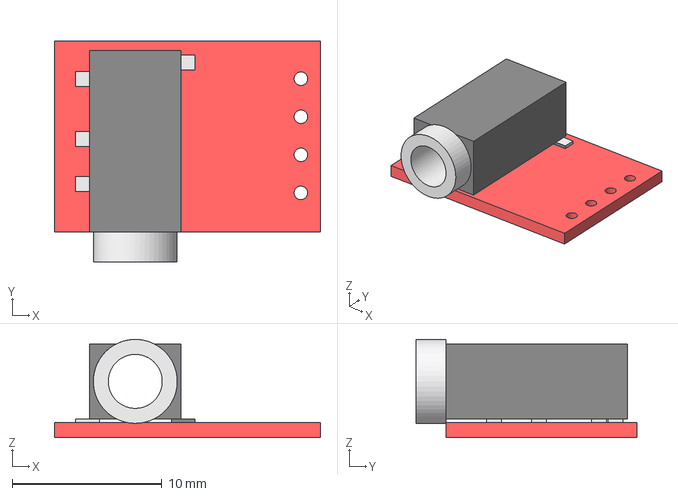
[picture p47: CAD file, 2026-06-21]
hardware/models/breakout.step
17.8 x 14.8 x 6.55 mm
TTRS20153
TRRSBreakoutNX

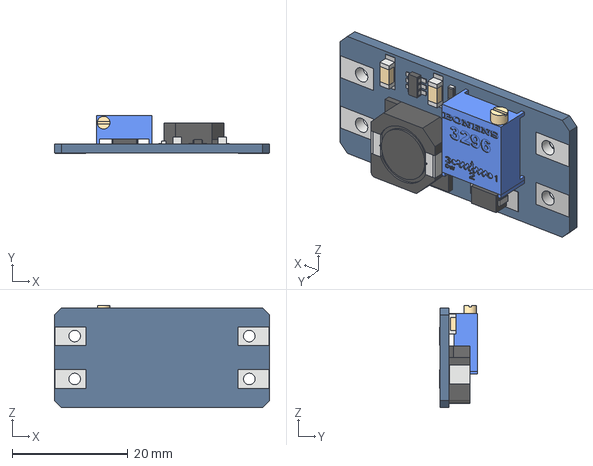
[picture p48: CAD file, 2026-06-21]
hardware/models/mt3608.step
37.2 x 6.49 x 17.7 mm

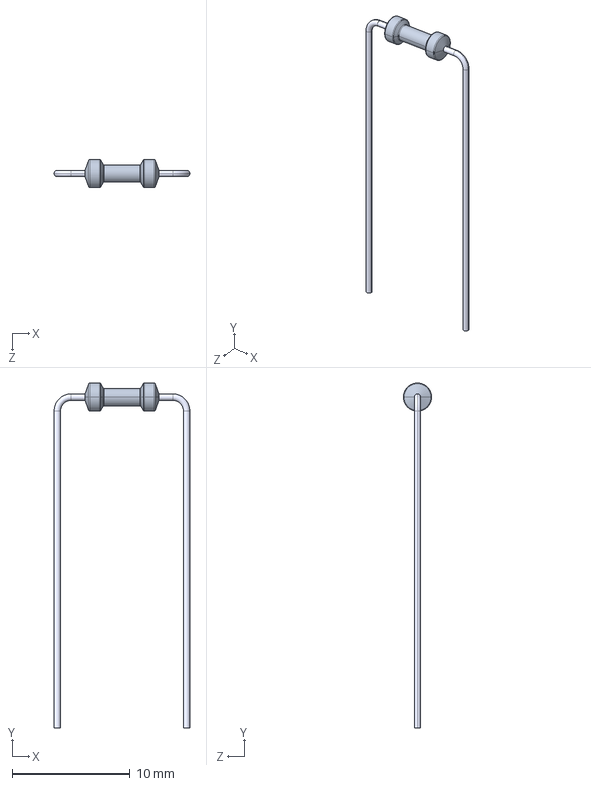
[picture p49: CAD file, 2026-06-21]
hardware/models/resistor.step
11.5 x 29.4 x 2.40 mm

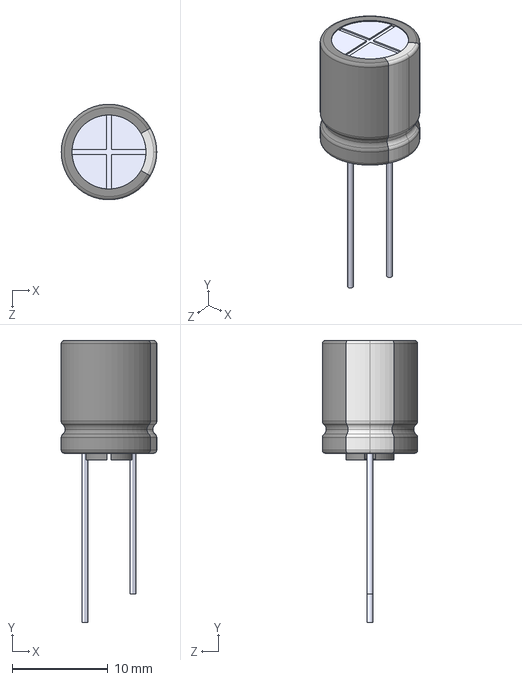
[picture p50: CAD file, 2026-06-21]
hardware/models/capacitor_100u.step
10.0 x 29.5 x 9.99 mm

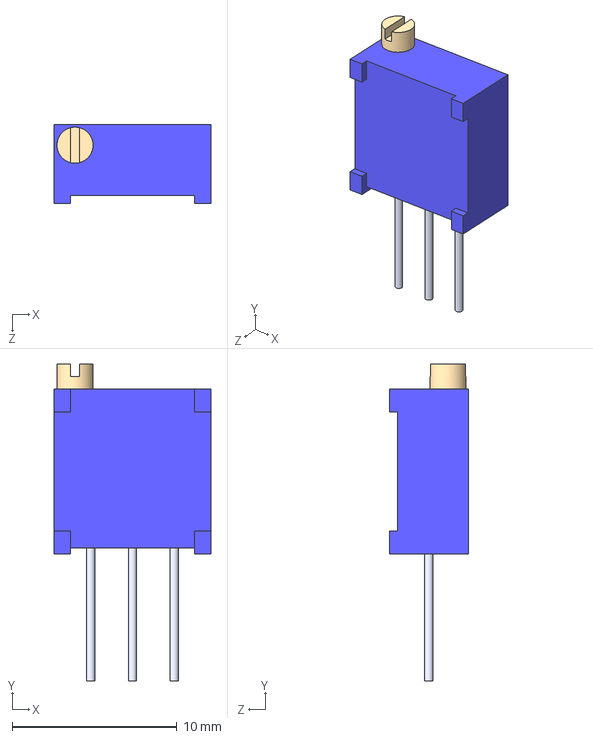
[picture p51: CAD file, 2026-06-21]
hardware/models/trimpot.step
9.53 x 19.3 x 4.83 mm

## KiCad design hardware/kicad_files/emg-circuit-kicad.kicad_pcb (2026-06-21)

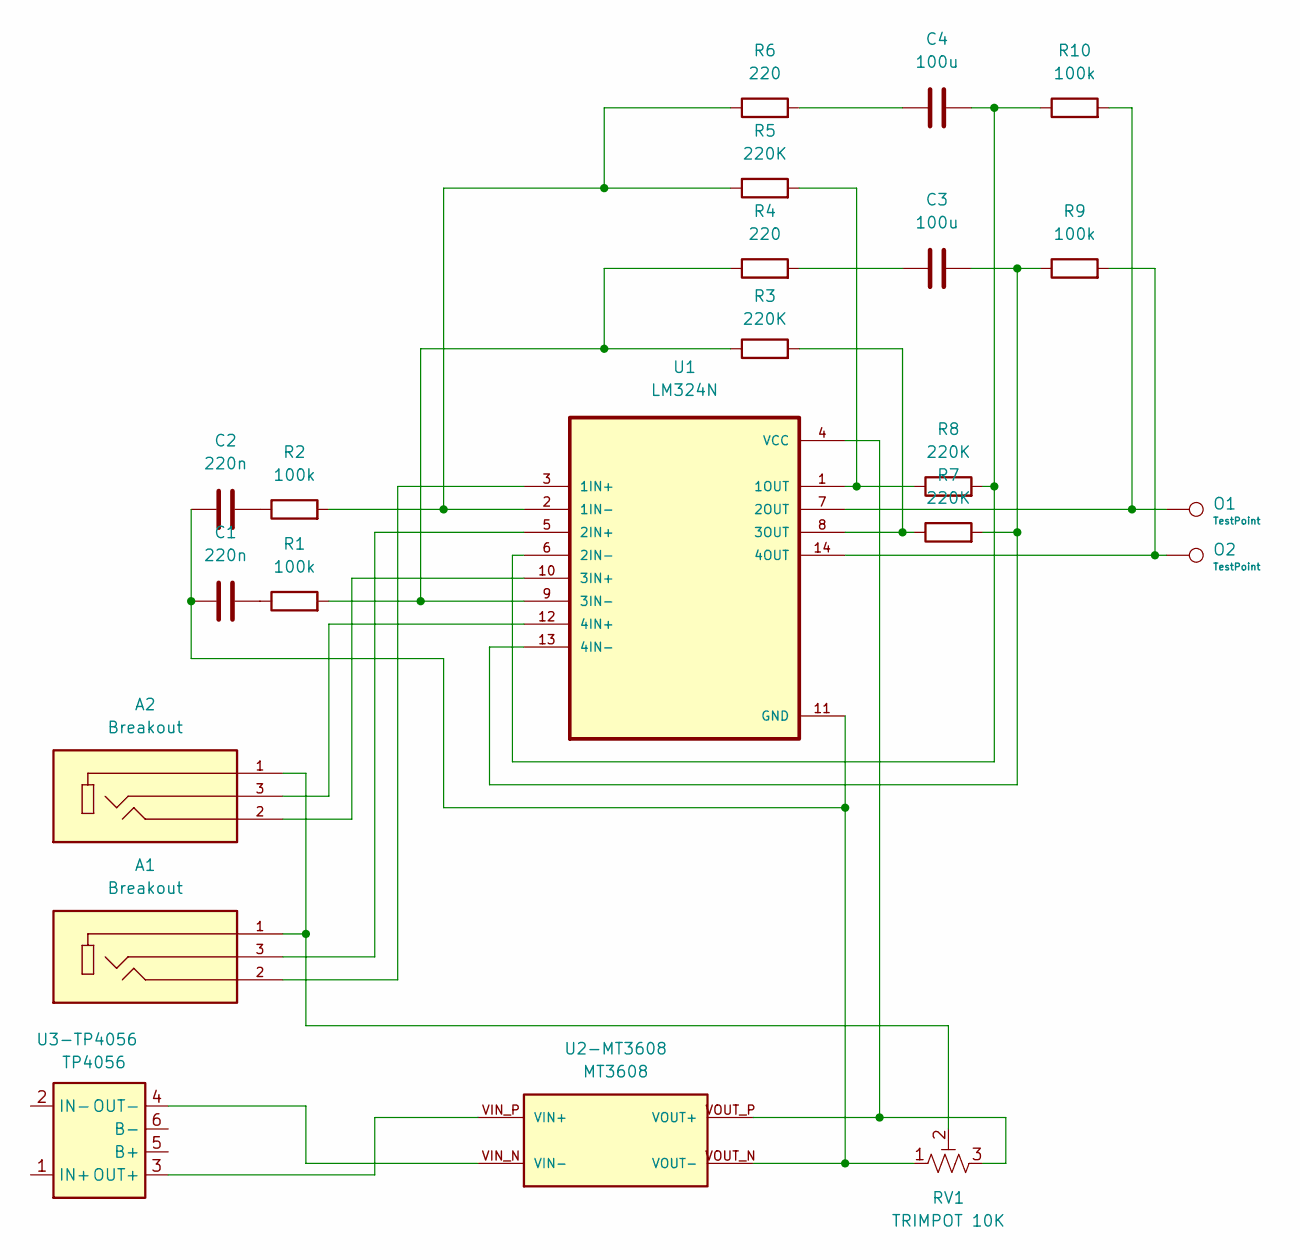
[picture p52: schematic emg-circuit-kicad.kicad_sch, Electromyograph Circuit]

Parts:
A1, A2: Breakout; breakout; PARTREV 1.01
C1, C2: 220n; capacitor_220n
C3, C4: 100u; capacitor_100u
O1, O2: TestPoint; TestPoint_THTPad_1.5x1.5mm_Drill0.7mm
R1, R2, R9, R10: 100k; resistor
R3, R5, R7, R8: 220K; resistor
R4, R6: 220; resistor
RV1: TRIMPOT 10K; trimpot
U1: LM324N; lm324
U2-MT3608: MT3608; mt3608
U3-TP4056: TP4056; tp4056

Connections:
unnamed: A1.1, A2.1, RV1.2
unnamed: C1.2, R1.1
unnamed: C2.2, R2.1
unnamed: C3.1, R4.2
unnamed: C4.1, R6.2
unnamed: A1.2, U1.3 (1IN+)
unnamed: R2.2, R5.1, R6.1, U1.2 (1IN-)
unnamed: R5.2, R8.1, U1.1 (1OUT)
unnamed: A1.3, U1.5 (2IN+)
unnamed: C4.2, R8.2, R10.1, U1.6 (2IN-)
unnamed: O1.1 (1_1), R10.2, U1.7 (2OUT)
unnamed: A2.2, U1.10 (3IN+)
unnamed: R1.2, R3.1, R4.1, U1.9 (3IN-)
unnamed: R3.2, R7.1, U1.8 (3OUT)
unnamed: A2.3, U1.12 (4IN+)
unnamed: C3.2, R7.2, R9.1, U1.13 (4IN-)
unnamed: O2.1 (1_1), R9.2, U1.14 (4OUT)
unnamed: C1.1, C2.1, RV1.1, U1.11 (GND), U2-MT3608.VOUT_N (VOUT-)
unnamed: RV1.3, U1.4 (VCC), U2-MT3608.VOUT_P (VOUT+)
unnamed: U2-MT3608.VIN_P (VIN+), U3-TP4056.3 (OUT+)
unnamed: U2-MT3608.VIN_N (VIN-), U3-TP4056.4 (OUT-)

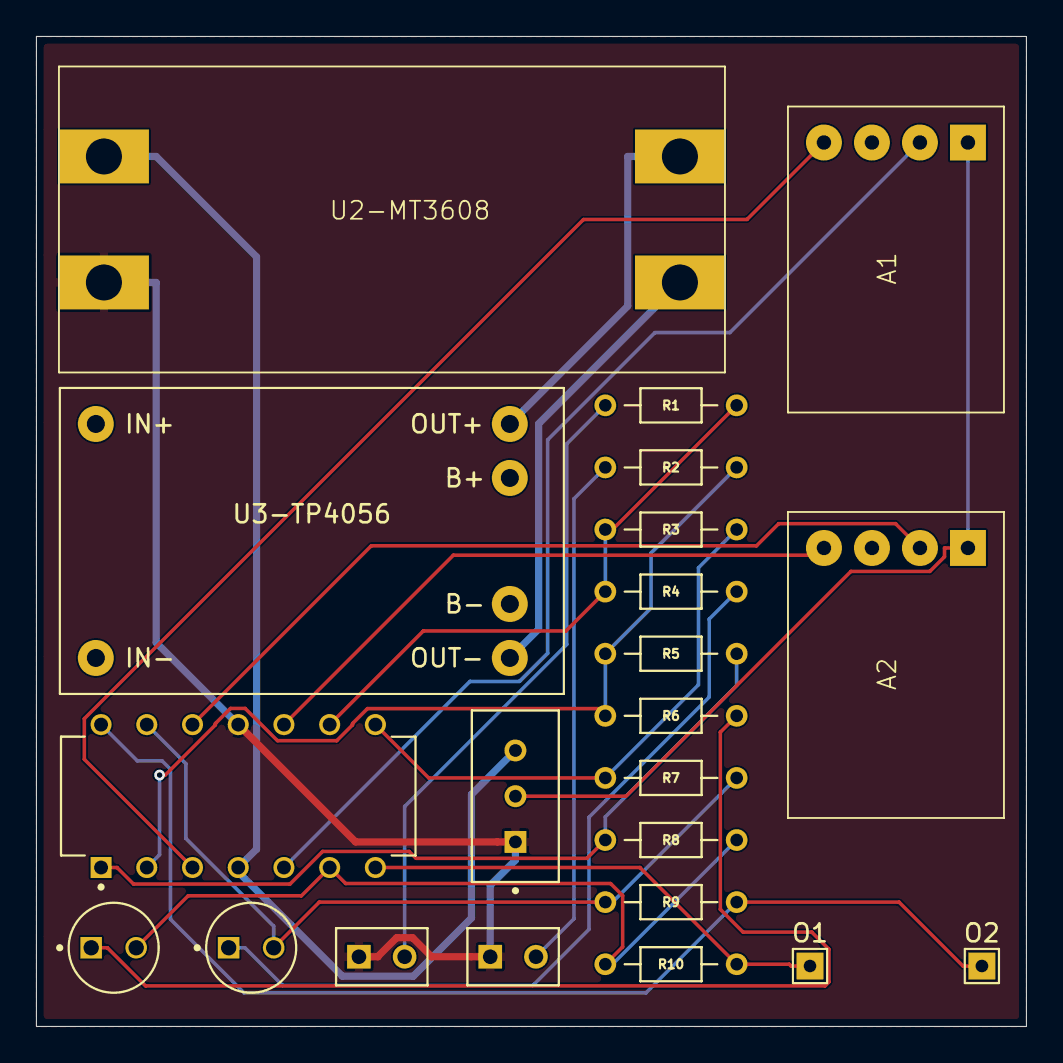
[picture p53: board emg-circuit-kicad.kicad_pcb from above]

Board: 2 copper layers, 55.0 x 55.0 mm, 22 parts (0 on the bottom side), 21 nets.

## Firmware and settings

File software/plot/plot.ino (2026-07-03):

#include <WiFi.h>
#include <WebServer.h>
#include <WebSocketsServer.h>

unsigned long last_time = 0;

//----------------------------------------------------------------------------------
// Defines
//----------------------------------------------------------------------------------

#ifndef SSID
    #define SSID "YOUR_SSID"
#endif
#ifndef PASSWORD
    #define PASSWORD "YOUR_PASSWORD"
#endif
#ifndef READ_MS
    #define READ_MS 20
#endif

WebServer server(80);
WebSocketsServer webSocket(81);

//----------------------------------------------------------------------------------
// HTML Page
//----------------------------------------------------------------------------------

const char HTML[] PROGMEM = R"=====(
<!DOCTYPE html>
<html>
    <head>
        <meta charset="UTF-8">
        <title>EMG</title>
        <script src="https://cdn.plot.ly/plotly-2.26.0.min.js"></script>
        <style>
            html, body {
                margin: 0;
                padding: 0;
                height: 100vh;
                width: 100vw;
                overflow: hidden;
                font-family: sans-serif;
            }

            body {
                display: flex;
                flex-direction: column;
            }

            main {
                flex-grow: 1;
                display: flex;
                flex-direction: column;
                padding: 10px 20px;
                box-sizing: border-box;
                gap: 10px;
            }

            .banner-container {
                display: flex;
                justify-content: center;
                align-items: center;
                height: 140px;
                flex-shrink: 0;
            }

            .banner-container img {
                max-height: 120px;
                object-fit: contain;
            }

            .plot-div {
                flex: 1;
                min-height: 0;
            }

        </style>
    </head>
    <body>
        <div class="banner-container">
            <img src="https://raw.githubusercontent.com/pontarolo/2026.1_DEC0013_EMG-INTEGRATED-WITH-AN-ESP32-WEB-SERVER/main/images/banner_3.png" height="120">
        </div>
        <main>
            <div id="channel-div" class="plot-div"></div>
        </main>
        <script>
            const channel = document.getElementById('channel-div');
            const points = 300;
    
            Plotly.newPlot(channel, [{y: [], mode: 'lines', line: {color: '#880808', width: 4}}], 
            {margin: {t: 40, b: 40, l: 50, r: 20},
            xaxis: {showgrid: false, zeroline: false, showticklabels: false},
            yaxis: {range: [0, 3.3], gridcolor: '#333', title: 'Voltage'}}, 
            {responsive: true, displayModeBar: false });

            const webSocket = new WebSocket('ws://' + location.hostname + ':81/');
            webSocket.binaryType = "arraybuffer";

            webSocket.onmessage = (e) => {
            if (e.data instanceof ArrayBuffer) {
                const view = new DataView(e.data);
                const ch_reading = view.getUint16(0, true) / 1000.0;
                Plotly.extendTraces(channel, { y: [[ch_reading]] }, [0], points);
            }};
</script>
</body></html>
)=====";

//----------------------------------------------------------------------------------
// Setup
//----------------------------------------------------------------------------------

uint16_t readEMG(uint8_t pin) {
    uint32_t sum = 0;
    for(int i = 0; i < 8; i++) {
        sum += analogReadMilliVolts(pin);
        delayMicroseconds(50);
    }
    return (uint16_t)(sum / 8);
}

void setup() {
    Serial.begin(115200);
    analogReadResolution(12);
    
    WiFi.setSleep(false);
    WiFi.begin(SSID, PASSWORD);
    
    while (WiFi.status() != WL_CONNECTED);
    
    Serial.println(WiFi.localIP());

    server.on("/", []() {
        server.send_P(200, "text/html", HTML);
    });

    server.begin();
    webSocket.begin();
}

//----------------------------------------------------------------------------------
// Main Loop
//----------------------------------------------------------------------------------

void loop() {
    server.handleClient();
    webSocket.loop();

    if (millis() - last_time >= READ_MS) {
        uint16_t reading = readEMG(35);
        delayMicroseconds(500);
        
        webSocket.broadcastBIN((uint8_t*)&reading, sizeof(reading));
        
        last_time = millis();
    }
}

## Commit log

2026-06-21 chore: init
    [breakout.step, capacitor_100u.step, capacitor_220n.step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]
2026-06-26 docs: change materials list
2026-06-26 docs: add pin reference
2026-06-26 docs: update resistors specifications
2026-06-28 docs: add pcb layout
2026-06-28 docs: move pcb layout
2026-06-28 docs: remove pcb layout
2026-07-03 docs: add final assembly photo
2026-07-09 docs: add pcb layout image
2026-07-09 docs: pcb layout image resizing
2026-07-10 docs: fix esp32 image

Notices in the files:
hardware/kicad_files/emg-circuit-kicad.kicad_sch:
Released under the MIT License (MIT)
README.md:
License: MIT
